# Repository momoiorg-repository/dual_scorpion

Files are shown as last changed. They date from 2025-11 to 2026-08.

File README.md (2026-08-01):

Dual_scorpion is the so-101 based integrated dual arm robot.
It is the independent fork of the so-101 design repository, and
is optimized for dual arm operation.
We added 2 DoF to the arm
created clavicle rod, spine and base.

dual_scorpion (CLI types `dual_scorpion_follower` and `dual_scorpion_leader`) extends the original SO-101 arm into a 7-DOF + gripper bimanual platform. The repository bundles printable parts, servo bring-up utilities, Hugging Face dataset hooks, and scripts for teleoperation, logging, and replay.

**References**
- Original SO-101 repository (Hugging Face LeRobot): https://github.com/huggingface/lerobot
- SO-101 hardware/software documentation on the Hugging Face Hub®: https://huggingface.co/docs/lerobot/so101
- Project overview video (YouTube): https://www.youtube.com/watch?v=a1u_bPGSeXs
- Hugging Face® is a registered trademark of Hugging Face, Inc.

## Meta Quest arm teleoperation

The isolated Telegrip WebXR add-on and its local/remote Quest setup guide are
in [`telegrip_teleoperation/`](telegrip_teleoperation/README.md). That folder
contains arm teleoperation only and reuses this repository's existing Dual
Scorpion follower driver.

## Contents
- [Highlights](#highlights)
- [Quickstart](#quickstart)
- [Parts for Dual Scorpion Leader and Follower](#parts-for-dual-scorpion-leader-and-follower)
- [Hardware Bring-Up](#hardware-bring-up)
- [Configuration](#configuration)
- [Runtime Workflows](#runtime-workflows)
- [3D Printed Parts](#3d-printed-parts)
- [Contributing](#contributing)
- [License](#license)

## Highlights
- Dual 7-DOF follower arms with matching leader arms for real-time bimanual control.
- CLI workflows (`lerobot-*`) cover motor setup, calibration, teleoperation, recording, and replay.
- Hugging Face integration stores demonstrations, policies, and evaluation runs.
- `dual_scorpion_3d_printer_parts/` ships STL files for both follower and leader builds.

## Quickstart

### Requirements
- Linux or macOS host with Python 3.12+.
- `pip`, `venv`, and a recent `git`.
- Feetech/BX servo buses (through the `[feetech]` extra).

### Install
```bash
git clone https://github.com/momoiorg-repository/dual_scorpion.git
cd dual_scorpion
python -m venv .venv
source .venv/bin/activate
pip install --upgrade pip
pip install -e ".[core_scripts,feetech]"
```

### Optional: authenticate with Hugging Face
```bash
hf auth login
export HF_USER=<your-hf-username>
```

## Parts for Dual Scorpion Leader and Follower

This list is for building the Dual Scorpion setup, including both the Leader and Follower arms.

For this version, all motors are standardized as **STS3215 Servo 7.4V, 19kg·cm, 1:345 gear ratio**.

- Leader: `(7 + 1) × 2 = 16 motors`
- Follower: `(7 + 1) × 2 = 16 motors`
- Total: `(7 + 1) × 4 = 32 motors`

The body frame is assembled using metal frames and connectors.
Cameras are not included in this parts list.

> * It is also possible to use the 12V version of the servo, depending on your design, power supply, and torque requirements.

| Part | Amount | Unit Cost (US) | Buy US | Unit Cost (JPY) | Buy JP |
| --- | ---: | ---: | --- | ---: | --- |
| STS3215 Servo 7.4V, 19kg·cm, 1:345 gear | 32 | $13.89 | [Alibaba](https://www.alibaba.com/product-detail/Top-Seller-Low-Cost-Feetech-STS3215_1600999461525.html) | ￥2,980 | [Akizuki Denshi](https://akizukidenshi.com/catalog/g/g116312/) |
| Motor Control Board | 4 | $10.6 | [Amazon US](https://www.amazon.com/Waveshare-Integrates-Control-Circuit-Supports/dp/B0CTMM4LWK/) | ￥980 | [Akizuki Denshi](https://akizukidenshi.com/catalog/g/g131227/) |

### Frame Parts

In Japan, these frame parts were purchased at a local home center, but they are also available online.

| Japan Part | Buy JP | US Equivalent | Reference |
| --- | --- | --- | --- |
| SGF-0004 | [G-Fun Japan](https://store.g-fun.jp/item/detail.php?ItemNo=SGF-0004) | GFF-000 | [SUS America GFF-000](https://www.susamericainc.com/products/detail.php?item_no=GFF-000) |
| SGF-0265 | [G-Fun Japan](https://store.g-fun.jp/item/detail.php?ItemNo=SGF-0265) | GFJ-200 | [SUS America GFJ-200](https://www.susamericainc.com/products/detail.php?item_no=GFJ-200) |

### Approximate Dimensions

For the current setup, the approximate dimensions are:

- Body/frame rod height: about 60 cm
- Setup width: about 30–45 cm
- Recommended width: 45 cm

These dimensions are still approximate and can be adjusted depending on the build.

### Notes

- This BOM focuses on the motors, motor control boards, and body frame parts.
- Camera parts are intentionally omitted from this list.
- The current Dual Scorpion setup uses only **STS3215 7.4V 19kg·cm 1:345** servos for consistency.
- The 12V version can also be used, but the power supply and wiring should be selected accordingly.

## Hardware Bring-Up
1. **Print & assemble** the follower and leader parts from `dual_scorpion_3d_printer_parts/`.
2. **Wire servos** to their controllers, mirroring IDs between left and right buses.
3. **Probe USB ports** (`lerobot-find-port`) to map `/dev/tty*` or `COM*` devices.

### Set Motor IDs
The wizard flashes IDs in this order: RIGHT gripper → joint6 … joint0, then LEFT gripper → joint6 … joint0.

- **Both arms (normal)**  
  ```bash
  lerobot-setup-motors \
    --robot.type=dual_scorpion_follower \
    --robot.left_arm_port=/dev/tty.usbmodemLEFT \
    --robot.right_arm_port=/dev/tty.usbmodemRIGHT
  ```

- **Left arm only** (right side ignored; dummy port OK)  
  ```bash
  lerobot-setup-motors \
    --robot.type=dual_scorpion_follower \
    --robot.left_arm_port=/dev/tty.usbmodem5A680111991 \
    --robot.right_arm_port=/dev/null \
    --arm left
  ```

- **Right arm only**  
  ```bash
  lerobot-setup-motors \
    --robot.type=dual_scorpion_follower \
    --robot.right_arm_port=/dev/tty.usbmodemRIGHT \
    --robot.left_arm_port=/dev/null \
    --arm right
  ```

Notes:
- `--arm` accepts `left`, `right`, or `both` (default).
- Keep both port flags; the unused side can point to `/dev/null` (macOS/Linux) or `NUL` (Windows).
- If `--arm` doesn’t show up in `--help`, ensure you’re using the project venv binary: `source .venv/bin/activate && rehash`.

### Calibrate Encoders
```bash
lerobot-calibrate \
  --robot.type=dual_scorpion_follower \
  --robot.left_arm_port=/dev/tty.usbmodemLEFT \
  --robot.right_arm_port=/dev/tty.usbmodemRIGHT \
  --robot.use_degrees=true
```
Follow the prompts to sweep every joint. Calibration artifacts are cached locally and reused by the runtime.

To redo only one joint while keeping the rest of an existing calibration JSON, pass `--joints`.
For Dual Scorpion, `joint5` is accepted as an alias for the internal `joint5` key (motor ID 6).

```bash
lerobot-calibrate \
  --robot.type=dual_scorpion_follower \
  --robot.left_arm_port=/dev/tty.usbmodemLEFT \
  --robot.right_arm_port=/dev/tty.usbmodemRIGHT \
  --robot.id=scorpion_follower_parallel_gripper \
  --robot.use_degrees=true \
  --joints=joint5

lerobot-calibrate \
  --teleop.type=dual_scorpion_leader \
  --teleop.left_arm_port=/dev/tty.usbmodemLEFT \
  --teleop.right_arm_port=/dev/tty.usbmodemRIGHT \
  --teleop.id=scorpion_leader_parallel_gripper \
  --teleop.use_degrees=true \
  --joints=joint5
```

Use `--joints=right_joint5` or `--joints=left_joint5` if only one arm should be updated.
Only the selected JSON entries are updated, but the selected arm's motors are unlocked during the
procedure so the joint can be moved by hand. The live table still shows every joint on that arm; selected
rows are marked with `*`.

## Configuration
All follower parameters live in `src/lerobot/robots/dual_scorpion_follower/config_dual_scorpion_follower.py`. Every `lerobot-*` CLI accepts the same keys via `--robot.*` flags, or you can instantiate the config directly:

```python
from lerobot.robots.dual_scorpion_follower import DualScorpionFollowerConfig

config = DualScorpionFollowerConfig(
    right_arm_port="/dev/tty.usbmodemRIGHT",
    left_arm_port="/dev/tty.usbmodemLEFT",
    disable_torque_on_disconnect=True,
    max_relative_target=12,
    cameras={
        "top": {
            "type": "opencv",
            "index_or_path": 0,
            "width": 640,
            "height": 480,
            "fps": 30,
        },
    },
    use_degrees=True,
)
```

Key fields:
- `right_arm_port` / `left_arm_port` – serial device assigned to each servo daisy-chain.
- `disable_torque_on_disconnect` – drop torque when the driver exits (protects hardware at rest).
- `max_relative_target` – per-joint clamp that keeps relative commands within a safe offset (can be scalar or a dict keyed by names such as `right_joint0`).
- `cameras` – optional `dict[str, CameraConfig]` used for streaming or logging.
- `use_degrees` – choose between degrees and normalized joint units.

## Runtime Workflows

### Teleoperate
```bash
lerobot-teleoperate \
  --robot.type=dual_scorpion_follower \
  --robot.left_arm_port=/dev/tty.usbmodemFOLLOWER_L \
  --robot.right_arm_port=/dev/tty.usbmodemFOLLOWER_R \
  --teleop.type=dual_scorpion_leader \
  --teleop.left_arm_port=/dev/tty.usbmodemLEADER_L \
  --teleop.right_arm_port=/dev/tty.usbmodemLEADER_R \
  --display_data=true
```
The leader mirrors joint commands to the follower while streaming configured cameras.

### Record Datasets
```bash
lerobot-record \
  --robot.type=dual_scorpion_follower \
  --robot.left_arm_port=/dev/tty.usbmodemFOLLOWER_L \
  --robot.right_arm_port=/dev/tty.usbmodemFOLLOWER_R \
  --teleop.type=dual_scorpion_leader \
  --teleop.left_arm_port=/dev/tty.usbmodemLEADER_L \
  --teleop.right_arm_port=/dev/tty.usbmodemLEADER_R \
  --robot.id=scorpion_follower \
  --teleop.id=scorpion_leader \
  --dataset.repo_id=${HF_USER}/dual_scorpion_demo \
  --dataset.single_task="Pick and place" \
  --dataset.num_episodes=10
```
Samples are written locally and pushed to the Hugging Face Hub when `HF_USER` is set.

### Replay Policies or Datasets
```bash
lerobot-replay \
  --robot.type=dual_scorpion_follower \
  --robot.left_arm_port=/dev/tty.usbmodemFOLLOWER_L \
  --robot.right_arm_port=/dev/tty.usbmodemFOLLOWER_R \
  --dataset.repo_id=${HF_USER}/dual_scorpion_demo \
  --dataset.episode=0
```

## 3D Printed Parts
`dual_scorpion_3d_printer_parts/` hosts the STL sets for both follower and leader builds (base plates, spine, clavicle rods, wrists, grippers, etc.).

## Acknowledgments
Dual_scorpion is designed based on the design of so-101. The development team of so-101 agreed to create a derivative model, and we are deeply grateful to them.
- Built on the SO-101 open-hardware design from the Hugging Face LeRobot project (https://github.com/huggingface/lerobot).
- Documentation and calibration guidance reference the official SO-101 guide on the Hugging Face Hub® (https://huggingface.co/docs/lerobot/so101).
- This derivative work remains under the Apache License 2.0 in alignment with the upstream project’s licensing.

## Contributing
Issues and PRs are encouraged—especially around documentation gaps, new teleop tooling, and CAD improvements. Please open an issue before large hardware or API changes so we can coordinate on interfaces.

## License
Apache License 2.0 (see `LICENSE`). Use the assets freely within the terms, and consider sharing back improvements to benefit other dual_scorpion builders.

**Author:** CHEN JUNGMING (陳俊銘)

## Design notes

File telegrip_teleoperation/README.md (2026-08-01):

# Telegrip Quest teleoperation

This folder is a standalone WebXR teleoperation add-on for the two Dual
Scorpion follower arms. It contains only the Quest/keyboard input path,
Cartesian IK, the arm hardware adapter, the browser UI, and the two URDFs
needed by the IK solver. It does not include recording, replay, training,
policies, cameras, speech, mobile-base, or lift control.

The implementation is adapted from the MIT-licensed
[Telegrip project](https://github.com/DipFlip/telegrip). See [LICENSE](LICENSE).
The URDF assets retain their Apache-2.0 license in [URDF/LICENSE](URDF/LICENSE).

## Safety

- Put both arms in a supported rest pose and clear the workspace before
  connecting.
- Test first with `telegrip --no-robot --no-viz`.
- Keep a person next to the robot and within reach of power.
- The browser is not an emergency stop. Remove motor power for an emergency.
- Robot connection is deliberately manual: open the web UI and select
  **Connect Robot** only when it is safe for the arms to move.

## Install

Telegrip reuses this repository's existing Dual Scorpion follower driver; it
does not ship another robot implementation.

```bash
git clone https://github.com/momoiorg-repository/dual_scorpion.git
cd dual_scorpion

python3.12 -m venv .venv
source .venv/bin/activate
pip install --upgrade pip
pip install -e ".[core_scripts,feetech]"
pip install -e ./telegrip_teleoperation
```

Open `telegrip_teleoperation/config.yaml` and set:

```yaml
robot:
  left_arm:
    port: /dev/serial/by-id/<left-controller>
  right_arm:
    port: /dev/serial/by-id/<right-controller>
```

Use `lerobot-find-port` to identify each controller. Calibrate the follower
with the repository's normal `lerobot-calibrate` workflow before connecting
Telegrip. No calibration files, serial numbers, certificates, or telemetry
logs are included in this folder.

## Local Quest teleoperation

Local mode has the lowest latency.

1. Connect the Quest and robot computer to the same LAN/Wi-Fi.
2. From the repository root:

   ```bash
   source .venv/bin/activate
   cd telegrip_teleoperation
   ./scripts/start_local.sh
   ```

3. On the Quest, open the printed `https://<robot-ip>:8443` URL. You can also
   use the stable bookmark below after the script updates it.
4. Accept the self-signed certificate warning, select **Enter VR**, verify both
   controllers track, and then select **Connect Robot**.

If the Quest cached an older UI, close the tab and reopen it or perform a hard
refresh.

## Remote Quest teleoperation

Remote mode creates temporary Cloudflare Quick Tunnel URLs for the HTTPS UI
and secure WebSocket. Quick Tunnels are convenient but do not add application
authentication; anyone who receives the active URL can reach the teleoperation
UI. Use a named Cloudflare Tunnel with access controls for unattended or
production use.

Install `cloudflared` and authenticate GitHub CLI once:

```bash
gh auth login
```

Then run:

```bash
source .venv/bin/activate
cd telegrip_teleoperation
./scripts/start_remote.sh
```

The script:

1. starts Telegrip locally;
2. creates separate HTTPS and WebSocket tunnels;
3. writes the current WebSocket hostname to `web-ui/ws_config.js`;
4. updates the stable Quest gist with local and remote links; and
5. stops both tunnels when Telegrip exits or you press Ctrl+C.

## Quest bookmark / GitHub gist

Bookmark this one time in Meta Quest Browser:

<https://gist.github.com/ammarjmahmood/a84200f82fd9618213d05f27e1c255ff>

The gist is secret/unlisted, not access-controlled. Publishing or sharing that
URL allows others to view its current link. The helper uses gist ID
`a84200f82fd9618213d05f27e1c255ff`; override it with
`TELEGRIP_GIST_ID=<id>` if you create a different gist.

For a manual update:

```bash
./scripts/publish_quest_link.sh \
  "https://<current-remote-host>.trycloudflare.com" \
  "https://<robot-lan-ip>:8443"
```

## Quest controls

- Hold left/right **grip**: move that arm relative to the controller pose.
- Hold left/right **trigger**: close that gripper; release to open.
- Hold right **A + B** for 3 seconds: home both arms.
- Hold left **X + Y** for 3 seconds: move both arms to the rest pose.
- Click either thumbstick: toggle the robot diagnostic shadow.

Both controllers use full-pose IK with all seven body joints enabled. No body
joint is locked in the default configuration.

Use `control.operator_to_robot_yaw_deg` in `config.yaml` to align operator
forward with the robot frame. Change it in 90-degree steps and restart.

## Useful commands

```bash
# Browser/IK test without hardware
telegrip --no-robot --no-viz

# Direct startup without the helper scripts
telegrip --no-viz \
  --left-port /dev/serial/by-id/<left-controller> \
  --right-port /dev/serial/by-id/<right-controller>
```

Runtime TLS files (`cert.pem`, `key.pem`), generated tunnel configuration, and
session telemetry are ignored by Git.

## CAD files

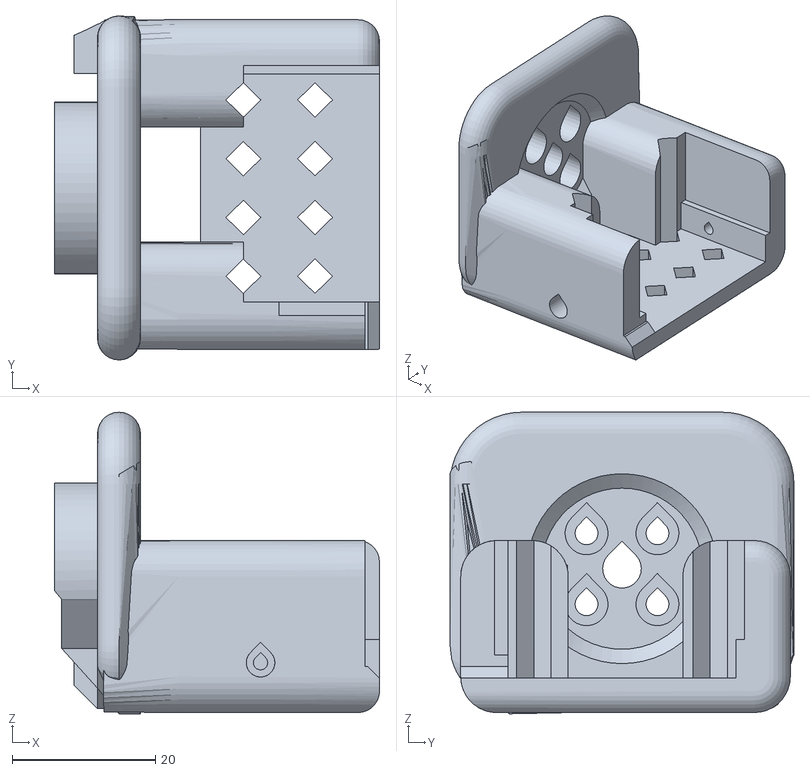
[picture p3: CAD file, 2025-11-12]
dual_scorpion_3d_printer_parts/follower/joint2_new_dof_reverse_L.stl
45.4 x 48.0 x 42.1

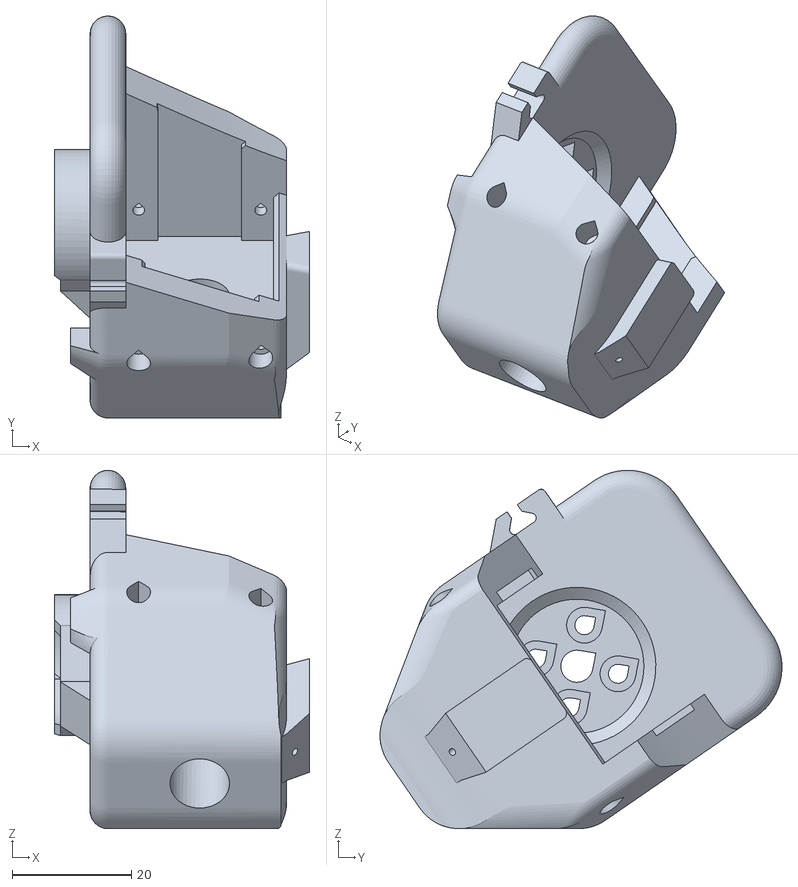
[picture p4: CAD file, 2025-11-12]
dual_scorpion_3d_printer_parts/leader/jpint7_gripper_mount_R.stl
42.9 x 67.4 x 60.1

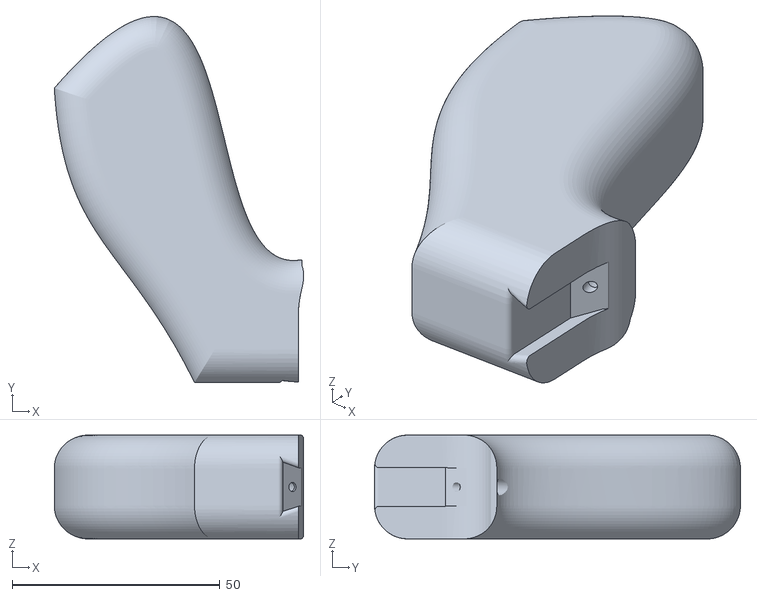
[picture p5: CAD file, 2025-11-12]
dual_scorpion_3d_printer_parts/leader/jpint7_gripper_hand_L.stl
60.1 x 88.1 x 25.0

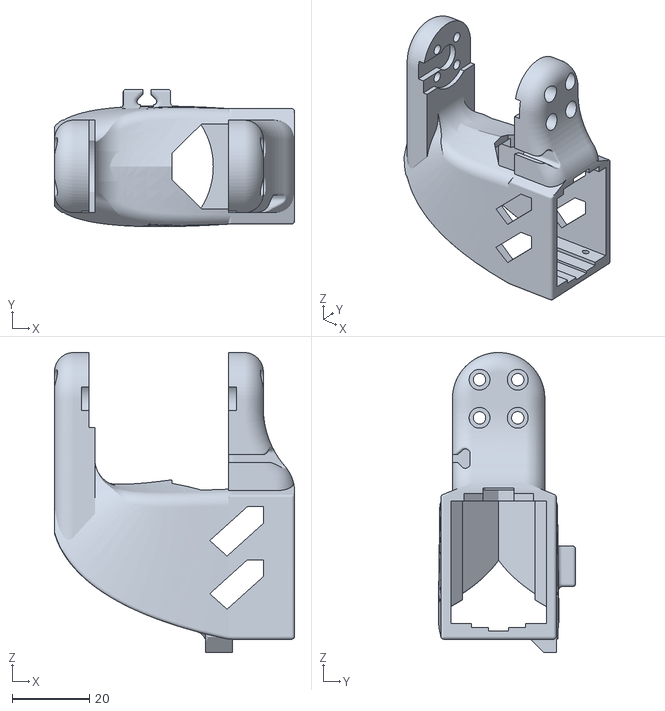
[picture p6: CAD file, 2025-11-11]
dual_scorpion_3d_printer_parts/follower/joint6_wrist_roll_pitch_reverse_L.stl
62.3 x 35.7 x 77.8

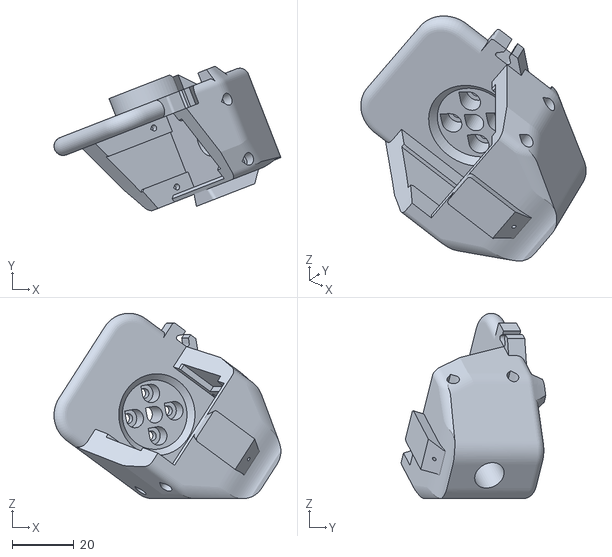
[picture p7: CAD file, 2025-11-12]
dual_scorpion_3d_printer_parts/leader/jpint7_gripper_mount_reverse_L.stl
73.6 x 46.9 x 60.1

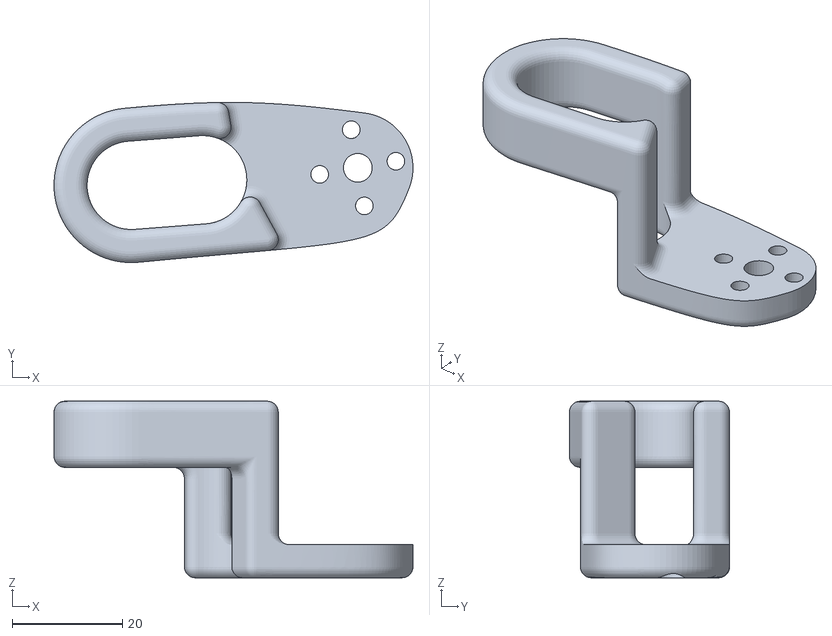
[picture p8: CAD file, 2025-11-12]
dual_scorpion_3d_printer_parts/leader/jpint7_gripper_trigger_L.stl
65.0 x 29.0 x 32.0

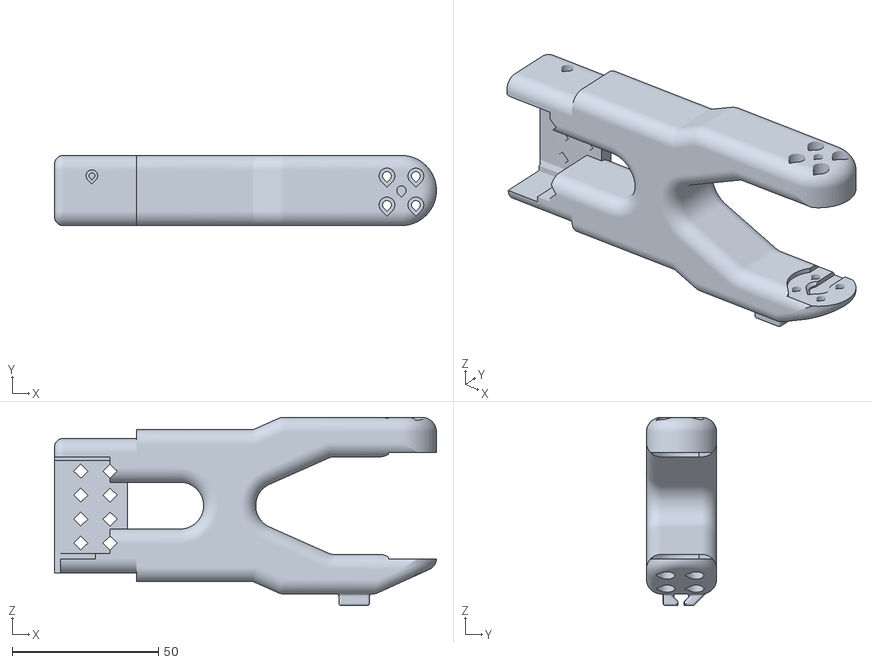
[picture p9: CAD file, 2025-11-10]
dual_scorpion_3d_printer_parts/follower/joint3_under_arm_R.stl
130.7 x 24.0 x 64.4

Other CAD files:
dual_scorpion_3d_printer_parts/follower/joint6_wrist_roll_pitch_R.stl
dual_scorpion_3d_printer_parts/follower/joint1_wrist_roll_pitch_R.stl
dual_scorpion_3d_printer_parts/follower/base.stl
dual_scorpion_3d_printer_parts/follower/joint0_cover1_L.stl
dual_scorpion_3d_printer_parts/follower/joint0_cover1_R.stl
dual_scorpion_3d_printer_parts/follower/joint0_motor_mount_L.stl
dual_scorpion_3d_printer_parts/follower/joint0_motor_mount_R.stl
dual_scorpion_3d_printer_parts/follower/joint2_new_dof_R.stl
dual_scorpion_3d_printer_parts/follower/joint4_wrist_roll_pitch_L.stl
dual_scorpion_3d_printer_parts/follower/joint7_gripper_moving_jaw_L.stl
dual_scorpion_3d_printer_parts/follower/joint7_gripper_moving_jaw_R.stl
dual_scorpion_3d_printer_parts/follower/joint7_wrist_roll_follower_L.stl
dual_scorpion_3d_printer_parts/follower/joint7_wrist_roll_follower_R.stl
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

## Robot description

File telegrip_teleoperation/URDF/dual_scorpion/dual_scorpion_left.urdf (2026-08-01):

<?xml version='1.0' encoding='utf-8'?>
<robot name="dual_scorpion_left">
  <link name="base_link">
    <inertial>
      <mass value="0.00166433" />
      <origin xyz="0.00273527 0.000514622 0.2002" rpy="0 -0 0" />
      <inertia ixx="7.05433e-05" ixy="-5.34831e-09" ixz="-1.25577e-06" iyy="0.000103998" iyz="-2.36418e-07" izz="3.62521e-05" />
    </inertial>
  </link>
  <link name="left_link_1">
    <inertial>
      <mass value="6.81805e-05" />
      <origin xyz="-0.0276923 0.000184201 -0.0352935" rpy="0 -0 0" />
      <inertia ixx="2.33205e-08" ixy="-5.08551e-11" ixz="-4.67906e-09" iyy="4.04588e-08" iyz="1.41441e-11" izz="2.65882e-08" />
    </inertial>
  </link>
  <joint name="joint0" type="revolute">
    <origin xyz="0.2923 0.0015 0.3967" rpy="-2.77106e-24 1.07852e-32 1.54074e-33" />
    <axis xyz="-1 0 0" />
    <parent link="base_link" />
    <child link="left_link_1" />
    <limit effort="1" velocity="1" lower="-1.41372" upper="1.50098" />
  </joint>
  <link name="ds_urdf_v4_1">
    <inertial>
      <mass value="5.16059e-09" />
      <origin xyz="0.0232251 0.000155884 -0.005982" rpy="0 -0 0" />
      <inertia ixx="0" ixy="0" ixz="0" iyy="0" iyz="0" izz="0" />
    </inertial>
  </link>
  <joint name="joint1" type="revolute">
    <origin xyz="-0.0199967 2.95597e-15 -0.061" rpy="-1.17484e-16 2.77556e-17 1.36056e-09" />
    <axis xyz="0 0 1" />
    <parent link="left_link_1" />
    <child link="ds_urdf_v4_1" />
    <limit effort="1" velocity="1" lower="-3.05433" upper="3.05433" />
  </joint>
  <link name="left_link_3">
    <inertial>
      <mass value="0.000129163" />
      <origin xyz="0.0198183 -0.00122104 -0.0746289" rpy="-2.27773e-07 0 0" />
      <inertia ixx="2.1178e-07" ixy="-8.61521e-11" ixz="-2.27068e-09" iyy="2.41179e-07" iyz="-7.83696e-09" izz="4.3049e-08" />
    </inertial>
  </link>
  <joint name="joint2" type="revolute">
    <origin xyz="-0.0183109 -0.0030748 -0.060508" rpy="2.53056e-16 5.7629e-18 -1.88737e-19" />
    <!-- Axis flipped: joint2 was rotating the wrong way on the left arm. -->
    <axis xyz="-1 0 0" />
    <parent link="ds_urdf_v4_1" />
    <child link="left_link_3" />
    <limit effort="1" velocity="1" lower="-1.74533" upper="2.0944" />
  </joint>
  <link name="left_link_4">
    <inertial>
      <mass value="6.81805e-05" />
      <origin xyz="0.0125077 0.000184201 -0.0352935" rpy="0 -0 0" />
      <inertia ixx="2.33205e-08" ixy="-5.08551e-11" ixz="-4.67906e-09" iyy="4.04588e-08" iyz="1.41441e-11" izz="2.65882e-08" />
    </inertial>
  </link>
  <joint name="joint3" type="revolute">
    <origin xyz="0.0008 -0.00520003 -0.1348" rpy="-1.5708 1.39556e-18 -4.95715e-18" />
    <axis xyz="1 0 0" />
    <parent link="left_link_3" />
    <child link="left_link_4" />
    <limit effort="1" velocity="1" lower="-0.523599" upper="3.31613" />
  </joint>
  <link name="ds_urdf_v4">
    <inertial>
      <mass value="0.0203158" />
      <origin xyz="9.96272e-05 -0.00461138 -0.0316214" rpy="0 0 -0.0119469" />
      <inertia ixx="1.11361e-05" ixy="7.87506e-08" ixz="-2.22606e-08" iyy="1.29317e-05" iyz="-4.43108e-07" izz="6.34939e-06" />
    </inertial>
  </link>
  <joint name="joint4" type="revolute">
    <origin xyz="0.0202033 2.95597e-15 -0.061" rpy="-1.4286e-18 -1.23156e-16 -2.91434e-16" />
    <axis xyz="0 0 1" />
    <parent link="left_link_4" />
    <child link="ds_urdf_v4" />
    <limit effort="1" velocity="1" lower="-2.95511" upper="2.97901" />
  </joint>
  <link name="left_link_6">
    <inertial>
      <mass value="6.81805e-05" />
      <origin xyz="-0.0276923 0.000184201 -0.0352935" rpy="0 -0 0" />
      <inertia ixx="2.33205e-08" ixy="-5.0855e-11" ixz="-4.67906e-09" iyy="4.04588e-08" iyz="1.41442e-11" izz="2.65882e-08" />
    </inertial>
  </link>
  <joint name="joint5" type="revolute">
    <origin xyz="0.018551 -0.00329665 -0.060508" rpy="-8.12727e-12 -3.1739e-19 -0.0119469" />
    <!-- Axis flipped: joint5 was rotating the wrong way on the left arm. -->
    <axis xyz="-1 0 0" />
    <parent link="ds_urdf_v4" />
    <child link="left_link_6" />
    <limit effort="1" velocity="1" lower="-1.74533" upper="2.0944" />
  </joint>
  <link name="left_link_7">
    <inertial>
      <mass value="9.28108e-05" />
      <origin xyz="0.00574692 0.000295973 -0.0266679" rpy="0 -0 0" />
      <inertia ixx="4.24859e-08" ixy="5.6838e-10" ixz="9.38588e-09" iyy="6.02663e-08" iyz="-1.16022e-10" izz="4.01829e-08" />
    </inertial>
  </link>
  <joint name="joint6" type="revolute">
    <origin xyz="-0.0199967 2.98372e-15 -0.061" rpy="1.05879e-22 3.17281e-19 -4.33681e-18" />
    <axis xyz="0 0 1" />
    <parent link="left_link_6" />
    <child link="left_link_7" />
    <limit effort="1" velocity="1" lower="-2.96706" upper="2.96706" />
  </joint>
  <link name="left_gripper_link">
    <inertial>
      <mass value="2.06928e-05" />
      <origin xyz="0.00157467 0.0186244 -0.0300229" rpy="0 -0 0" />
      <inertia ixx="1.14047e-08" ixy="-1.01886e-11" ixz="5.51271e-10" iyy="9.11649e-09" iyz="1.89574e-10" izz="3.25975e-09" />
    </inertial>
  </link>
  <joint name="gripper" type="revolute">
    <origin xyz="-0.0202033 -0.0181 -0.0234" rpy="-1.20731e-16 1.3606e-09 -2.78336e-15" />
    <axis xyz="0 1 0" />
    <parent link="left_link_7" />
    <child link="left_gripper_link" />
    <limit effort="1" velocity="1" lower="-0.174533" upper="1.91986" />
  </joint>
  <link name="tcp_link">
    <inertial>
      <mass value="0.001" />
      <origin xyz="0 0 0" rpy="0 0 0" />
      <inertia ixx="1e-7" ixy="0" ixz="0" iyy="1e-7" iyz="0" izz="1e-7" />
    </inertial>
  </link>
  <joint name="tcp_fixed" type="fixed">
    <origin xyz="-0.019053 0.000900 -0.105400" rpy="0 0 0" />
    <parent link="left_link_7" />
    <child link="tcp_link" />
  </joint>
</robot>

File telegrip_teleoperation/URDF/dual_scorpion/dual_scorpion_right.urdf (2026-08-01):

<?xml version='1.0' encoding='utf-8'?>
<robot name="dual_scorpion_right">
  <link name="base_link">
    <inertial>
      <mass value="0.00166433" />
      <origin xyz="0.00273527 0.000514622 0.2002" rpy="0 -0 0" />
      <inertia ixx="7.05433e-05" ixy="-5.34831e-09" ixz="-1.25577e-06" iyy="0.000103998" iyz="-2.36418e-07" izz="3.62521e-05" />
    </inertial>
  </link>
  <link name="right_link_1">
    <inertial>
      <mass value="6.81805e-05" />
      <origin xyz="0.0276923 0.000184203 -0.0352935" rpy="0 -0 0" />
      <inertia ixx="2.33205e-08" ixy="5.08562e-11" ixz="4.67906e-09" iyy="4.04588e-08" iyz="1.4143e-11" izz="2.65882e-08" />
    </inertial>
  </link>
  <joint name="joint0" type="revolute">
    <origin xyz="-0.277418 0.00138639 0.393411" rpy="-2.27782e-07 -0.0119469 2.72121e-09" />
    <!-- Axis flipped: joint0 was rotating the wrong way on the right arm. -->
    <axis xyz="-1 0 0" />
    <parent link="base_link" />
    <child link="right_link_1" />
    <limit effort="1" velocity="1" lower="-1.41372" upper="1.50098" />
  </joint>
  <link name="right_link_2">
    <inertial>
      <mass value="6.51728e-05" />
      <origin xyz="-0.00042288 -0.00438565 -0.0344568" rpy="0 -0 0" />
      <inertia ixx="2.93177e-08" ixy="-9.50406e-11" ixz="3.84639e-11" iyy="3.41703e-08" iyz="-1.46217e-10" izz="1.48858e-08" />
    </inertial>
  </link>
  <joint name="joint1" type="revolute">
    <origin xyz="0.0199967 2.95597e-15 -0.061" rpy="-1.19112e-22 -2.60209e-18 -1.36056e-09" />
    <!-- Axis flipped: joint1 was rotating the wrong way on the right arm. -->
    <axis xyz="0 0 -1" />
    <parent link="right_link_1" />
    <child link="right_link_2" />
    <limit effort="1" velocity="1" lower="-3.05433" upper="3.05433" />
  </joint>
  <link name="right_link_3">
    <inertial>
      <mass value="0.000129163" />
      <origin xyz="-0.0198183 -0.001221 -0.0746288" rpy="2.27757e-07 -0 0" />
      <inertia ixx="2.11781e-07" ixy="8.61386e-11" ixz="2.27034e-09" iyy="2.4118e-07" iyz="-7.8369e-09" izz="4.30491e-08" />
    </inertial>
  </link>
  <joint name="joint2" type="revolute">
    <origin xyz="0.0183109 -0.00307479 -0.060508" rpy="-4.46e-17 -1.58727e-16 1.38777e-17" />
    <!-- Axis flipped: joint2 was rotating the wrong way on the right arm. -->
    <axis xyz="1 0 0" />
    <parent link="right_link_2" />
    <child link="right_link_3" />
    <limit effort="1" velocity="1" lower="-2.09439" upper="1.74533" />
  </joint>
  <link name="right_link_4">
    <inertial>
      <mass value="6.81805e-05" />
      <origin xyz="0.0276923 0.000184203 -0.0352935" rpy="0 -0 0" />
      <inertia ixx="2.33205e-08" ixy="5.08562e-11" ixz="4.67906e-09" iyy="4.04588e-08" iyz="1.4143e-11" izz="2.65882e-08" />
    </inertial>
  </link>
  <joint name="joint3" type="revolute">
    <origin xyz="-0.0377 -0.00519997 -0.1348" rpy="-1.5708 3.84241e-16 -1.20677e-16" />
    <axis xyz="1 0 0" />
    <parent link="right_link_3" />
    <child link="right_link_4" />
    <limit effort="1" velocity="1" lower="-0.349066" upper="3.31613" />
  </joint>
  <link name="right_link_5">
    <inertial>
      <mass value="6.51728e-05" />
      <origin xyz="-0.000370457 -0.00439039 -0.0344568" rpy="0 -0 0.0119469" />
      <inertia ixx="2.93207e-08" ixy="-1.52981e-10" ixz="4.02087e-11" iyy="3.41673e-08" iyz="-1.45747e-10" izz="1.48858e-08" />
    </inertial>
  </link>
  <joint name="joint4" type="revolute">
    <origin xyz="0.0199967 2.91434e-15 -0.061" rpy="6.02058e-17 1.65148e-18 1.73472e-18" />
    <axis xyz="0 0 1" />
    <parent link="right_link_4" />
    <child link="right_link_5" />
    <limit effort="1" velocity="1" lower="-2.97901" upper="2.95511" />
  </joint>
  <link name="right_link_6">
    <inertial>
      <mass value="6.81805e-05" />
      <origin xyz="-0.0125077 0.000184203 -0.0352935" rpy="0 -0 0" />
      <inertia ixx="2.33205e-08" ixy="5.08551e-11" ixz="4.67906e-09" iyy="4.04588e-08" iyz="1.41433e-11" izz="2.65882e-08" />
    </inertial>
  </link>
  <joint name="joint5" type="revolute">
    <origin xyz="0.0183464 -0.00285582 -0.060508" rpy="8.12663e-12 -7.31558e-26 0.0119469" />
    <axis xyz="-1 0 0" />
    <parent link="right_link_5" />
    <child link="right_link_6" />
    <limit effort="1" velocity="1" lower="-2.0944" upper="1.74533" />
  </joint>
  <link name="right_link_7">
    <inertial>
      <mass value="9.28112e-05" />
      <origin xyz="-0.00574682 0.000295823 -0.0266677" rpy="0 -0 0" />
      <inertia ixx="4.24859e-08" ixy="-5.68162e-10" ixz="-9.38597e-09" iyy="6.0266e-08" iyz="-1.15687e-10" izz="4.01834e-08" />
    </inertial>
  </link>
  <joint name="joint6" type="revolute">
    <origin xyz="-0.0202033 2.91434e-15 -0.061" rpy="-2.8453e-31 -9.56554e-42 -4.62593e-18" />
    <axis xyz="0 0 1" />
    <parent link="right_link_6" />
    <child link="right_link_7" />
    <limit effort="1" velocity="1" lower="-2.96706" upper="2.96706" />
  </joint>
  <link name="right_gripper_link">
    <inertial>
      <mass value="2.06928e-05" />
      <origin xyz="-0.00157468 0.0186244 -0.0300229" rpy="0 -0 0" />
      <inertia ixx="1.14047e-08" ixy="1.01887e-11" ixz="-5.51272e-10" iyy="9.1165e-09" iyz="1.89573e-10" izz="3.25975e-09" />
    </inertial>
  </link>
  <joint name="gripper" type="revolute">
    <origin xyz="0.0202033 -0.0181 -0.0234" rpy="9.95431e-26 1.36046e-09 4.62593e-18" />
    <axis xyz="0 1 0" />
    <parent link="right_link_7" />
    <child link="right_gripper_link" />
    <limit effort="1" velocity="1" lower="-1.91986" upper="0.174533" />
  </joint>
  <link name="tcp_link">
    <inertial>
      <mass value="0.001" />
      <origin xyz="0 0 0" rpy="0 0 0" />
      <inertia ixx="1e-7" ixy="0" ixz="0" iyy="1e-7" iyz="0" izz="1e-7" />
    </inertial>
  </link>
  <joint name="tcp_fixed" type="fixed">
    <origin xyz="0.019053 0.000900 -0.105400" rpy="0 0 0" />
    <parent link="right_link_7" />
    <child link="tcp_link" />
  </joint>
</robot>

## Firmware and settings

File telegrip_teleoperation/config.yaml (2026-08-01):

control:
  # Bench-calibrated yaw mapping "operator forward" (headset gaze direction
  # captured when grip engages) onto the robot base frame. -90 = operator
  # forward is robot -Y, the direction the arms extend outward - so pushing
  # the controller forward extends the arm outward (bench-verified Jul 16;
  # +90 made forward pull the arm inward/backward).
  # Adjust in 90-deg steps first if forward/sideways come out swapped.
  operator_to_robot_yaw_deg: -90
  # Cartesian controller motion is expressed in one shared robot world frame.
  # Mechanical left/right mirroring already lives in the two URDFs; reflecting
  # only one controller here gives the arms opposite translation and rotation
  # handedness. Keep both false unless the entire operator frame is mirrored.
  mirror_lateral:
    left: false
    right: false
  keyboard:
    angle_step: 5
    enabled: true
    gripper_step: 10.0
    pos_step: 0.01
  pybullet:
    enabled: true
  vr:
    enabled: true
    shadow_enabled_by_default: true
    controller_axes_enabled_by_default: true
gripper:
  closed_angle: 45.0
  open_angle: 0.0
ik:
  # Position-priority full-pose IK across all seven body joints. It seeds from
  # the current commanded pose so motion stays continuous, and the per-tick
  # slew limit below protects the physical arms from branch flips.
  # 0.5 deg/tick at 50 Hz = 25 deg/s. The previous 4 deg/tick permitted
  # 200 deg/s command ramps, much faster than the measured arm response.
  max_joint_step_deg: 0.5
  # If the FK-verified full-pose solution misses the target position by more
  # than this, the solve is repeated position-only (position beats orientation).
  position_tolerance_m: 0.02
  # Reachable-workspace sphere radius (m) around each shoulder (joint0).
  # Controller targets outside this sphere are projected onto its surface so
  # impossible targets never drive joints into their limits. The arm's true
  # max shoulder-to-TCP reach is ~0.53 m; 0.48 leaves margin while cutting the
  # constant boundary-riding seen in the Jul 17 left-arm session (86% of
  # solves were clamped at the old 0.45). Absolute max reach is 0.546 m; we
  # stop at 0.52 because a fully straight arm is a kinematic singularity
  # where IK becomes ill-conditioned and chatters.
  # Practical full reach. The URDF reaches 0.546 m, but stopping at 0.52 m
  # avoids the exactly-straight kinematic singularity while using nearly the
  # full physical arm length.
  workspace_radius_m: 0.52
  # Begin smoothly compressing radial hand motion before the straight-arm
  # singularity. Targets remain responsive instead of suddenly sticking to a
  # hard sphere at maximum reach.
  workspace_soft_start_m: 0.48
  # Max change (deg) of the orientation target per solve, measured from the
  # current TCP orientation (task-space slew limit). Prevents a large
  # accumulated orientation error (e.g. after a position-only stretch) from
  # unwinding the wrist in one violent burst - the "left arm rotating multiple
  # wrong ways" failure. 6 deg/solve at 50 Hz = up to 300 deg/s, still fast
  # enough to track normal wrist motion.
  orientation_slew_deg: 6
network:
  host_ip: 0.0.0.0
  https_port: 8443
  websocket_port: 8442
paths:
  urdf_left_path: URDF/dual_scorpion/dual_scorpion_left.urdf
  urdf_right_path: URDF/dual_scorpion/dual_scorpion_right.urdf
robot:
  left_arm:
    enabled: true
    name: Left Arm
    port: /dev/ttyACM1
  right_arm:
    enabled: true
    name: Right Arm
    port: /dev/ttyACM0
  # 0.02 = 50 Hz control/send rate. The Quest streams poses at ~72 Hz, so 20 Hz
  # (the old value) threw away most updates and made motion steppy/laggy. 50 Hz
  # is well within the serial budget for 16 servos at 1 Mbps.
  send_interval: 0.02
  # Controller-to-TCP translation gain. At 1.10, moving a controller 10 cm
  # moves the robot TCP 11 cm, making the compact workspace easier to cover
  # without a full human-arm reach. The workspace clamp remains the final
  # safety boundary.
  vr_to_robot_scale: 1.10
  # Per-arm controller-to-TCP rotation gain.
  vr_rotation_scale:
    left: 0.5
    right: 0.5
  # Full-pose controller orientation is enabled for both seven-joint arms.
  vr_orientation_enabled:
    left: true
    right: true
  # No body joints are locked; all seven joints participate in IK.
  locked_joints:
    left: {}
    right: {}
  # Translation remains position-only until controller rotation exceeds this
  # intentional-motion threshold, preventing IK wrist/shoulder twisting while
  # merely lifting a mostly straight controller.
  vr_orientation_deadband_deg: 8
  # Anti-windup: commanded joint angles may never lead the measured motor
  # angles by more than this (deg). If a motor stalls or lags badly, the
  # commanded state is pulled back to measured+limit so it stays anchored to
  # the physical arm and recovers instead of running away (Jul 17: left arm
  # commanded state froze 46 deg from the stalled motors for 5+ seconds).
  command_lag_limit_deg: 8
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

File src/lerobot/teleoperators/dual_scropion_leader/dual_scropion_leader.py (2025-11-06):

#!/usr/bin/env python

# Copyright 2025 The HuggingFace Inc. team. All rights reserved.
# Modifications Copyright 2025 S.Satoya
#
# Licensed under the Apache License, Version 2.0 (the "License");
# you may not use this file except in compliance with the License.
# You may obtain a copy of the License at
#
#     http://www.apache.org/licenses/LICENSE-2.0
#
# Unless required by applicable law or agreed to in writing, software
# distributed under the License is distributed on an "AS IS" BASIS,
# WITHOUT WARRANTIES OR CONDITIONS OF ANY KIND, either express or implied.
# See the License for the specific language governing permissions and
# limitations under the License.

import logging
import time

from lerobot.errors import DeviceAlreadyConnectedError, DeviceNotConnectedError
from lerobot.motors import Motor, MotorCalibration, MotorNormMode
from lerobot.motors.feetech import (
    FeetechMotorsBus,
    OperatingMode,
)

from ..teleoperator import Teleoperator
from .config_dual_scropion_leader import DualScropionLeaderConfig

logger = logging.getLogger(__name__)

class DualScropionLeader(Teleoperator):
    """
    Dual Scropion Leader Arm
    """
    config_class = DualScropionLeaderConfig    
    name = "dual_scropion_leader"

    def __init__(self, config: DualScropionLeaderConfig):
        """
        Initialize the Dual Scropion Leader Arm
        Dual Scropion 双腕リーダーアームを初期化
        """
        super().__init__(config)
        self.config = config
        norm_mode_body = MotorNormMode.DEGREES if config.use_degrees else MotorNormMode.RANGE_M100_100

        # Separate calibration data for right and left arms / キャリブレーションデータを右腕と左腕用に分離
        right_calibration = {
            motor.replace("right_", ""): calib 
            for motor, calib in self.calibration.items() 
            if motor.startswith("right_")
        }
        left_calibration = {
            motor.replace("left_", ""): calib 
            for motor, calib in self.calibration.items() 
            if motor.startswith("left_")
        }

        # Initialize right follower motors / 右腕のモーターバスの初期化
        self.right_bus = FeetechMotorsBus(
            port=self.config.right_arm_port,
            motors={
                "joint0": Motor(1, "sts3215", norm_mode_body),
                "joint1": Motor(2, "sts3215", norm_mode_body),
                "joint2": Motor(3, "sts3215", norm_mode_body),
                "joint3": Motor(4, "sts3215", norm_mode_body),
                "joint4": Motor(5, "sts3215", norm_mode_body),
                "joint5": Motor(6, "sts3215", norm_mode_body),
                "joint6": Motor(7, "sts3215", norm_mode_body),
                "gripper": Motor(8, "sts3215", MotorNormMode.RANGE_0_100),
            },
            calibration=right_calibration,
        )
        # Initialize left follower motors / 左腕のモーターバスの初期化
        self.left_bus = FeetechMotorsBus(
            port=self.config.left_arm_port,
            motors={
                "joint0": Motor(1, "sts3215", norm_mode_body),
                "joint1": Motor(2, "sts3215", norm_mode_body),
                "joint2": Motor(3, "sts3215", norm_mode_body),
                "joint3": Motor(4, "sts3215", norm_mode_body),
                "joint4": Motor(5, "sts3215", norm_mode_body),
                "joint5": Motor(6, "sts3215", norm_mode_body),
                "joint6": Motor(7, "sts3215", norm_mode_body),
                "gripper": Motor(8, "sts3215", MotorNormMode.RANGE_0_100),
            },
            calibration=left_calibration,
        )

    @property
    def action_features(self) -> dict[str, type]:
        """
        Returns the action features for the Dual Scropion Leader Arm.
        アクション特徴を返す
        """
        features = {}
        # Right arm motors / 右腕のモーター
        features.update({f"right_{motor}.pos": float for motor in self.right_bus.motors})
        #  Left arm motors / 左腕のモーター
        features.update({f"left_{motor}.pos": float for motor in self.left_bus.motors})
        return features
    
    @property
    def feedback_features(self) -> dict[str, type]:
        return {}
    
    @property
    def is_connected(self) -> bool:
        """
        Check if the devices is connected.
        デバイスが接続されているかを確認する
        """
        return self.right_bus.is_connected and self.left_bus.is_connected
    
    def connect(self, calibrate: bool = True) -> None:
        """
        Connect the devices.
        デバイスを接続する
        """
        if self.is_connected:  # 既に接続されている場合はエラーを投げる
            raise DeviceAlreadyConnectedError(f"{self} already connected")

        self.right_bus.connect()  # 右腕のモーターバスを接続
        self.left_bus.connect()  # 左腕のモーターバスを接続

        if not self.is_calibrated and calibrate:  # キャリブレーションが必要な場合は実行
            self.calibrate()

        self.configure()
        logger.info(f"{self} connected.")

    @property
    def is_calibrated(self) -> bool:
        """
        Check if the devices is calibrated.
        キャリブレーションが完了しているかを確認する
        """
        return self.right_bus.is_calibrated and self.left_bus.is_calibrated
    
    def calibrate(self) -> None:
        """
        Run calibration for the Dual Scropion Leader Arm.
        キャリブレーションを実行する
        """
        logger.info(f"\nRunning calibration for {self}")
        self.right_bus.disable_torque()  # 右腕のトルクを無効化
        self.left_bus.disable_torque()  # 左腕のトルクを無効化

        for motor in self.right_bus.motors:
            self.right_bus.write("Operating_Mode", motor, OperatingMode.POSITION.value)
        for motor in self.left_bus.motors:
            self.left_bus.write("Operating_Mode", motor, OperatingMode.POSITION.value)

        self.calibration = {}
        # Right arm calibration / 右腕のキャリブレーション 
        input(f"Move RIGHT {self} to the middle of its range of motion and press ENTER....")
        right_homing_offsets = self.right_bus.set_half_turn_homings()
        print(
            "Move all joints sequentially through their entire ranges "
            "of motion.\nRecording positions. Press ENTER to stop..."
        )
        right_range_mins, right_range_maxes = self.right_bus.record_ranges_of_motion()
        for motor, m in self.right_bus.motors.items():  # motor = "shoulder_pan", "shoulder_lift", ... | m = Motor instance
            self.calibration[f"right_{motor}"] = MotorCalibration(
                id=m.id,
                drive_mode=0,
                homing_offset=right_homing_offsets[motor],
                range_min=right_range_mins[motor],
                range_max=right_range_maxes[motor],
            )
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

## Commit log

2025-11-10 add base model stl file
    [base.stl]
2025-11-10 add joint0_motor_mount.stl
    [joint0_motor_mount.stl]
2025-11-10 add joint0_cover1.stl
    [joint0_cover1.stl]
2025-11-11 add model
    [wrist_roll_pitch_so101_v2_reverse.stl]
2025-11-12 add all model
    [joint0_cover1_L.stl, joint0_cover1_R.stl, joint0_motor_mount_L.stl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]
2026-10-27 fix: support motor direction inversion in degrees mode
2026-10-27 docs: add Dual Scorpion hardware photo and motor direction guide
2026-10-31 fix: include new follower STL parts
2026-10-31 feat: regenerate printable STL sets from Scorpion v11
